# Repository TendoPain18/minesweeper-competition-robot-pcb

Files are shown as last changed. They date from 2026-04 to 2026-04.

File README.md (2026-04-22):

# Minesweeper Competition Robot — PCB Design 🤖💣

Custom KiCad-designed PCBs for a minesweeper competition robot, consisting of a **Control PCB** housing the main microcontroller and sensing/driving circuitry, and a **Power PCB** acting as a smart relay system for safely switching robot subsystems on and off.

<div align="center">
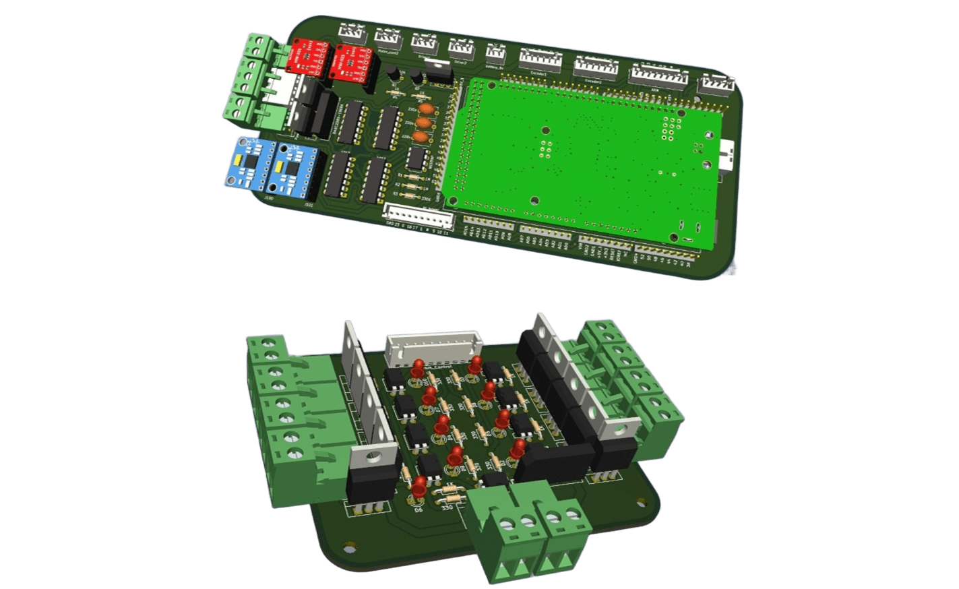
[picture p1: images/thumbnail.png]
Minesweeper Robot PCBs
  
</div>

<br>
<div align="center">
  <a href="https://codeload.github.com/TendoPain18/minesweeper-competition-robot-pcb/legacy.zip/main">
    
  </a>
</div>

## 📋 About

Both PCBs were fully designed from schematic to layout in **KiCad** and manufactured as real printed circuit boards. The two boards work together: the Control PCB handles all logic, motor driving, sensing, and protection, while the Power PCB receives switching commands from the Control PCB and safely controls power delivery to the robot's subsystems.

## 🛠️ Tools Used

- **KiCad** — Schematic capture and PCB layout
- **Arduino IDE** — Firmware for the Arduino Mega

---

## 🟦 Control PCB

The brain of the robot. Hosts the microcontroller and all peripheral circuitry needed to drive motors, read sensors, and manage safe shutdown.

<div align="center">
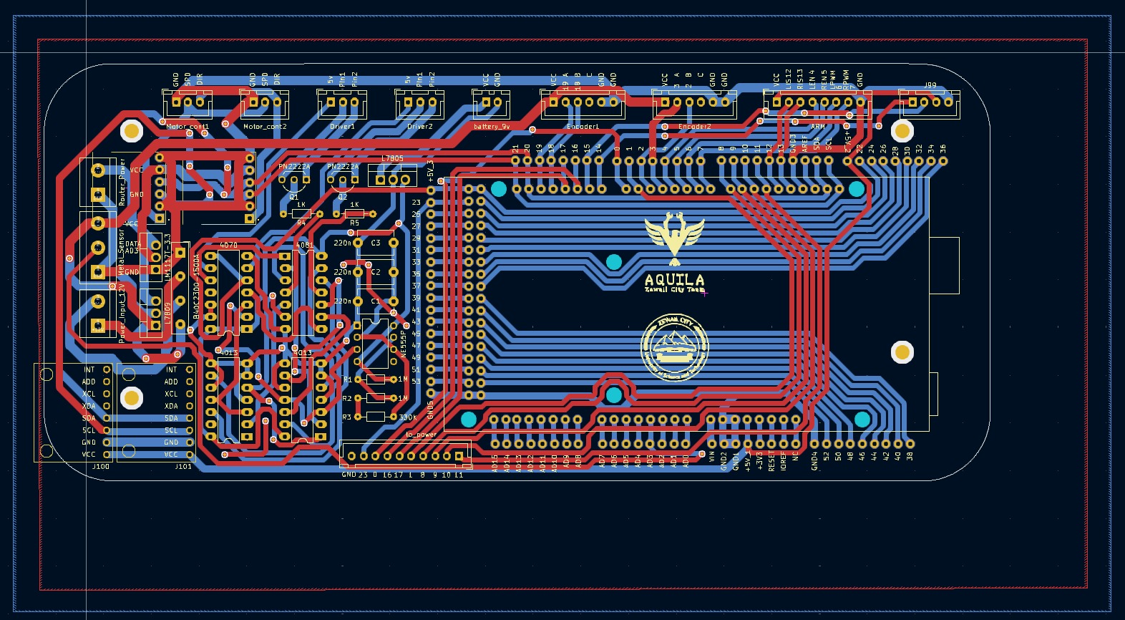
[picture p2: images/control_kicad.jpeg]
Control PCB KiCad Layout
  
</div>

<div align="center">
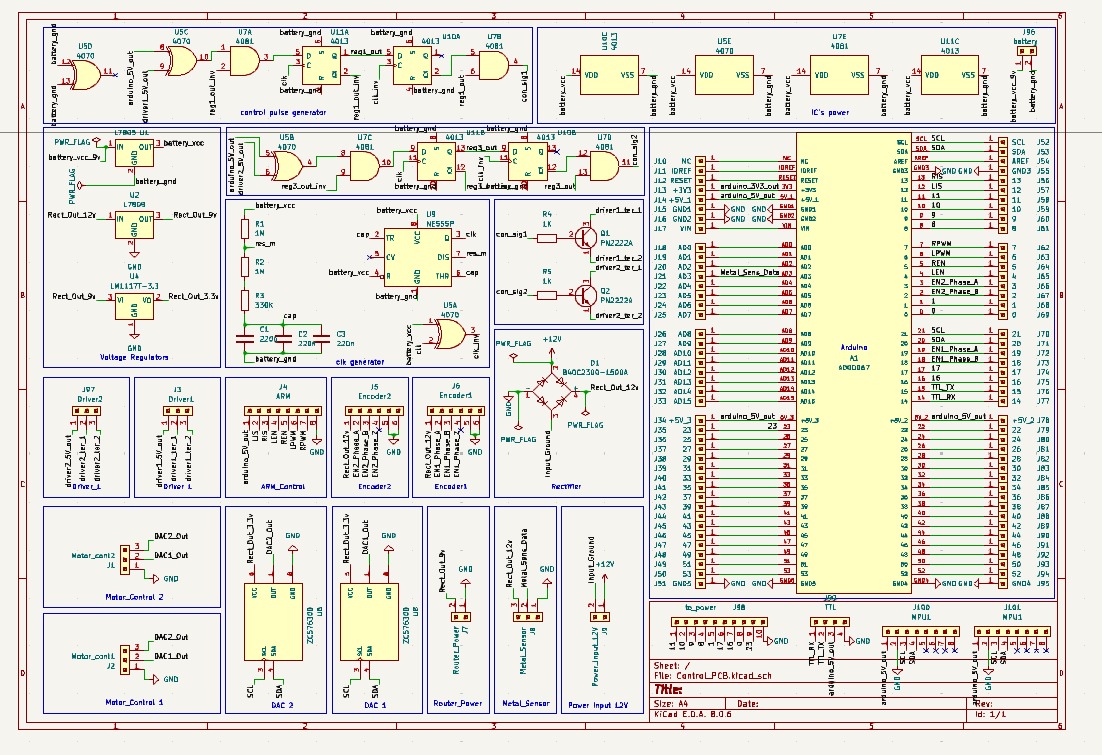
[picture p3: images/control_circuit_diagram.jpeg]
Control Circuit Diagram
  
</div>

### Key Components

- **Arduino Mega** — Main microcontroller
- **Two HW-315 Motor Driver Modules** — Drive the main locomotion motors
- **H-Bridge** — Additional motor driving stage
- **Two MPU-6050 IMUs** — Inertial measurement units for orientation sensing
- **Auto Safe-Shutdown Circuit** — Capacitor-backed circuit using ICs, capacitors, and resistors that detects power loss and safely closes the system before supply rails collapse

### Connector Pins / Interfaces

| Interface | Description |
|---|---|
| Motor Control ×2 | PWM/direction signals for drive motors |
| Motor Driver ×2 | Power outputs to HW-315 modules |
| Encoder ×2 | Quadrature encoder inputs for wheel odometry |
| Arm Motor | Control signal for the mine-detection arm |
| 9V Battery | Main power input |
| Power PCB Link | Control signals sent to the Power PCB |

### PCB Photos

<div align="center">
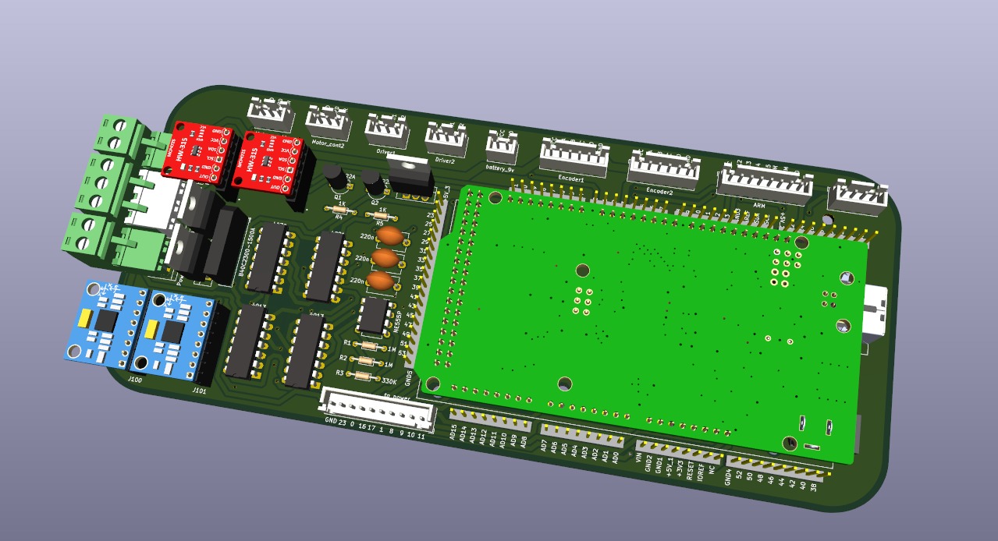
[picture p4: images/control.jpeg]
Control PCB
  
</div>

<div align="center">
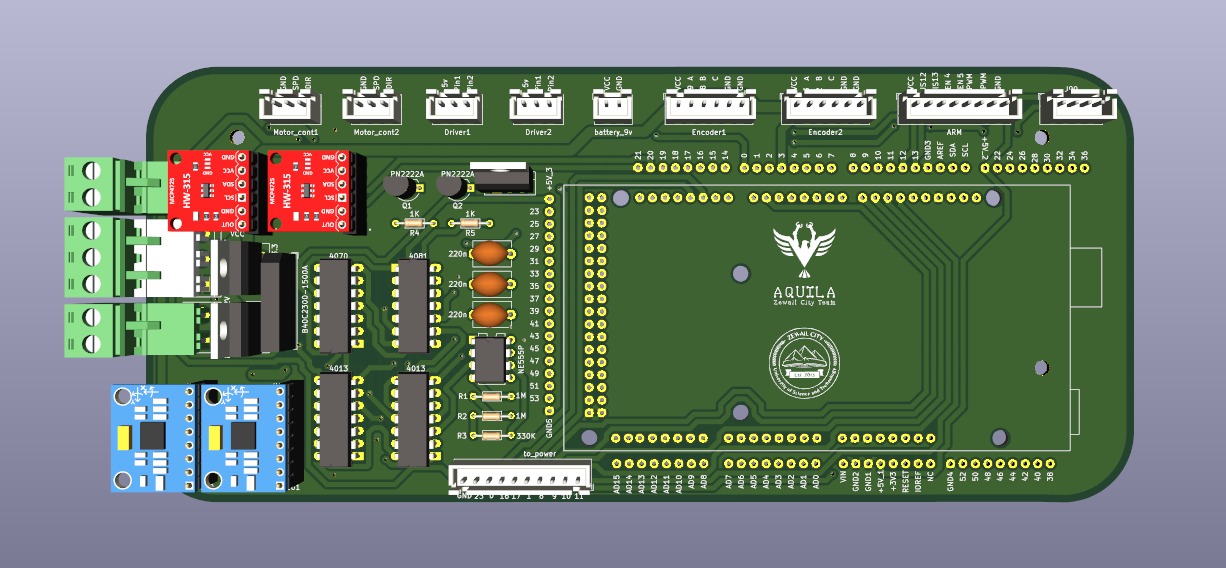
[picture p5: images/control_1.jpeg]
Control PCB View 1
  
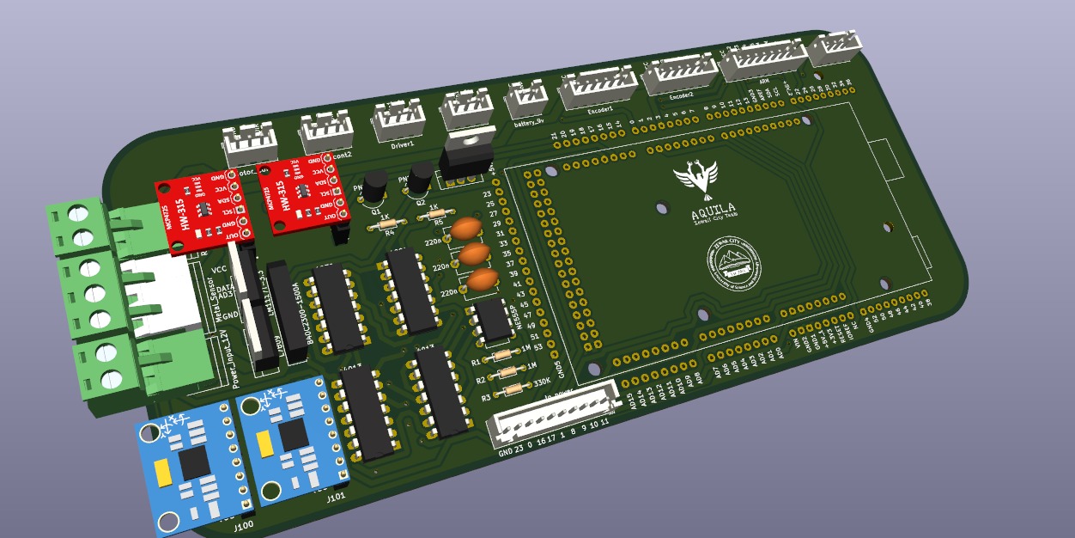
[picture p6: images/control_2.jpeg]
Control PCB View 2
  
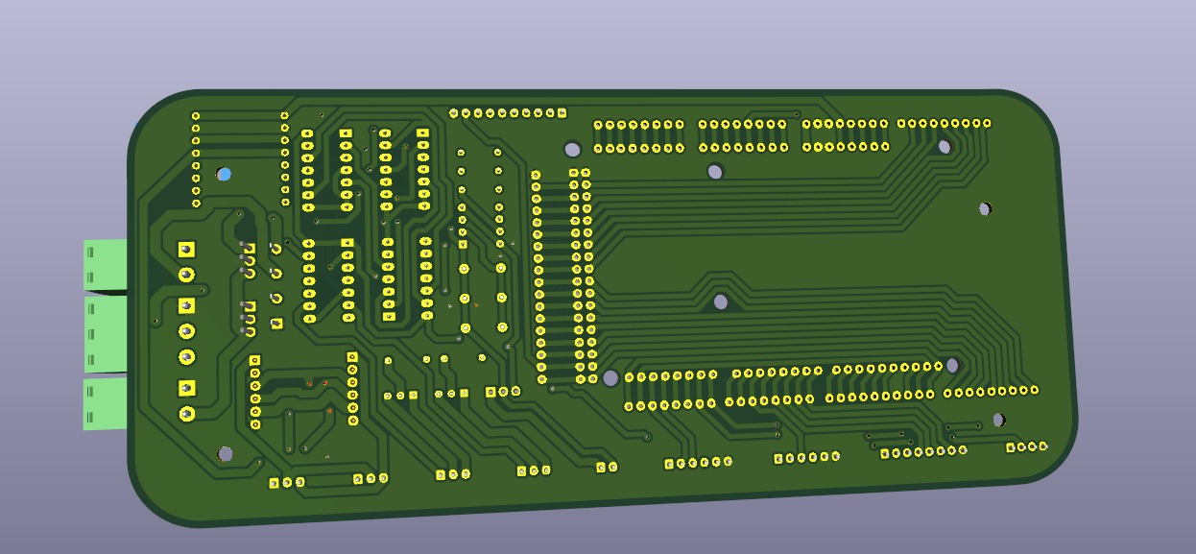
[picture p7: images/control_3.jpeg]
Control PCB View 3
  
</div>

### Safe Shutdown Circuit

A key protection feature of the Control PCB is the automatic safe-shutdown circuit. When the power supply is cut or drops below a safe threshold, the capacitor bank holds enough energy to allow the ICs to complete a controlled shutdown sequence, preventing state corruption and protecting the motor drivers from abrupt power loss.

---

## 🟥 Power PCB

Acts as a smart relay board, receiving switching signals from the Control PCB and toggling power to the robot's subsystems in a safe, controlled manner.

<div align="center">
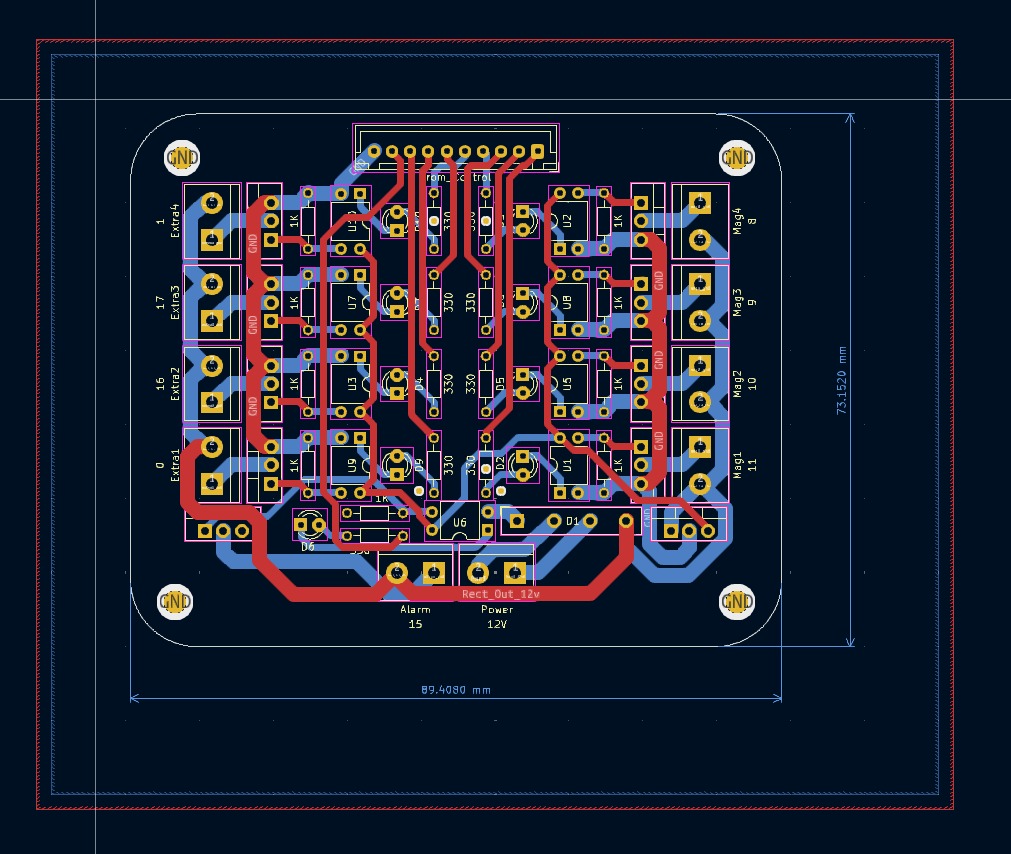
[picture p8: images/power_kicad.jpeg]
Power PCB KiCad Layout
  
</div>

<div align="center">
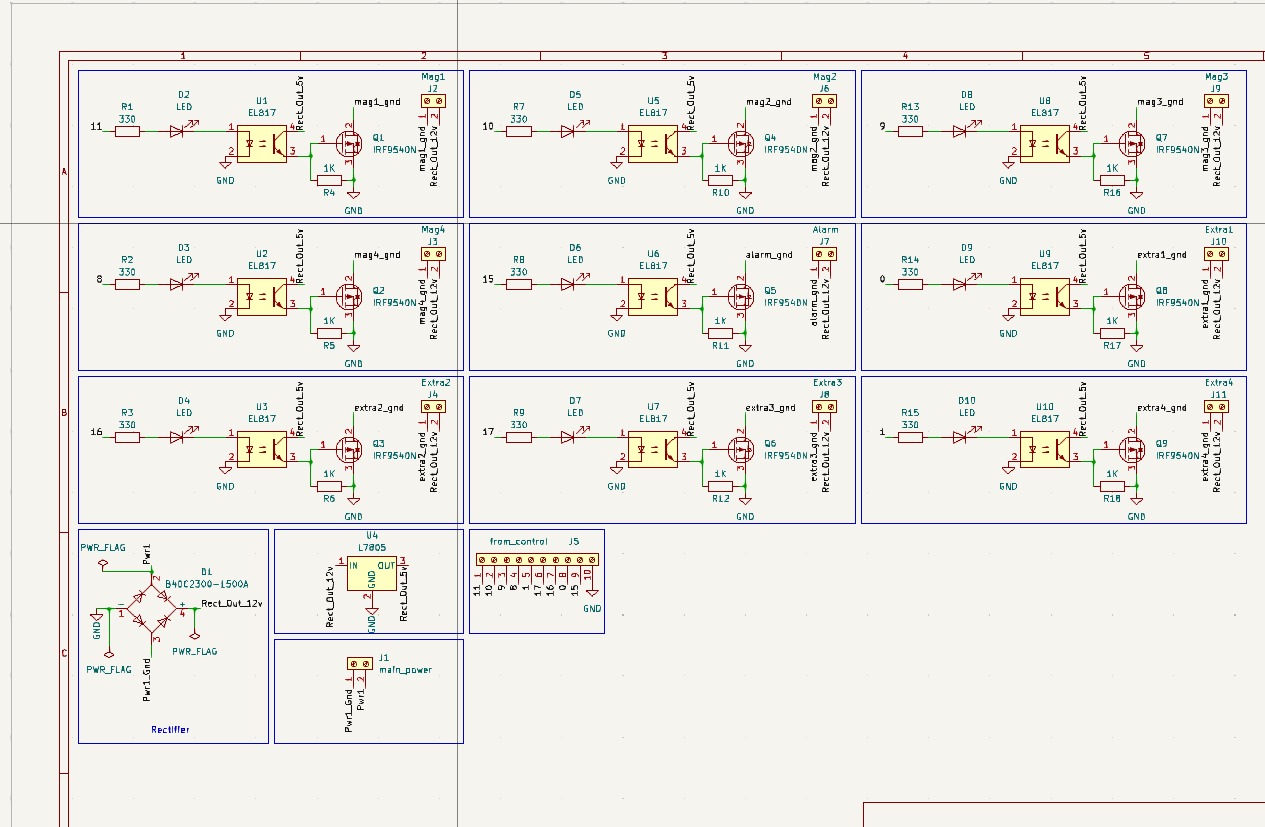
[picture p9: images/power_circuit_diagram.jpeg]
Power Circuit Diagram
  
</div>

### Key Features

- Receives control signals from the Control PCB
- Safely switches power to robot subsystems on and off
- Protects against back-EMF and switching transients
- Designed for low-resistance power paths to minimise losses

### PCB Photos

<div align="center">
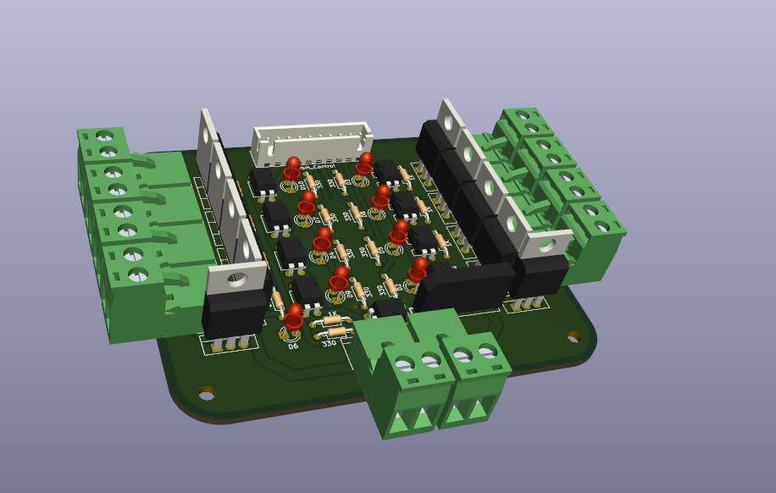
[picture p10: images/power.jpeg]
Power PCB
  
</div>

<div align="center">
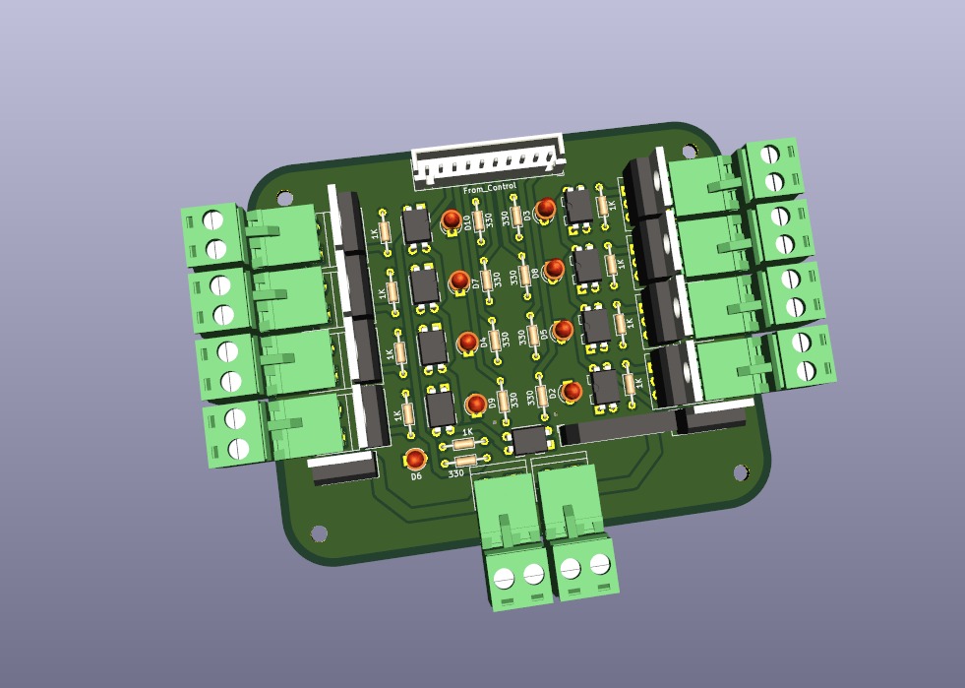
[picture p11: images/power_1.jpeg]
Power PCB View 1
  
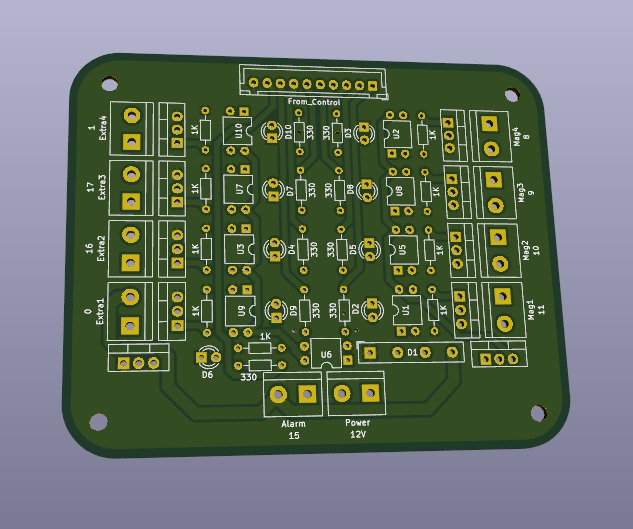
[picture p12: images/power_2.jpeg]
Power PCB View 2
  
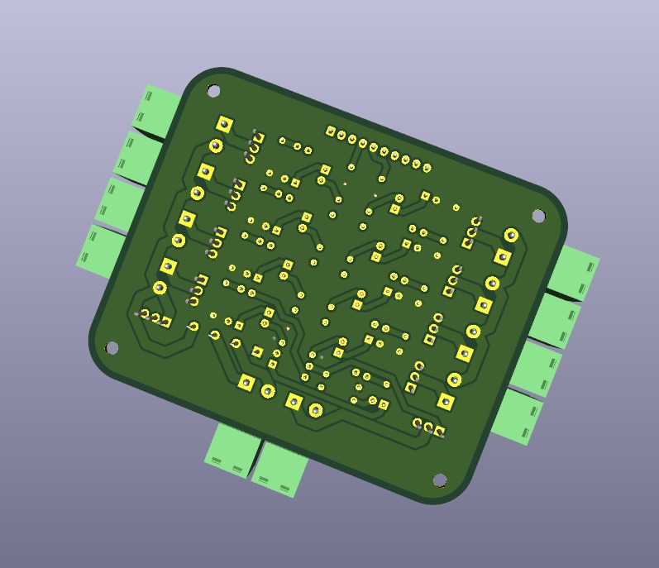
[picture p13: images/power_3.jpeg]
Power PCB View 3
  
</div>

---

## 🖨️ Manufactured Boards

<div align="center">
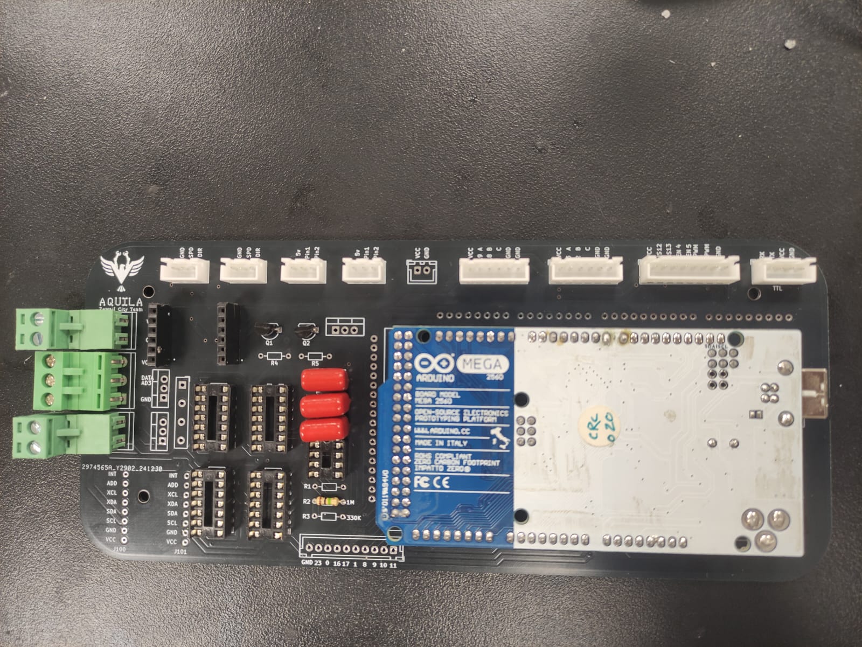
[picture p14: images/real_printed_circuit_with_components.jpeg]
Real Printed Circuit with Components
  
</div>

*Fully assembled and populated PCBs ready for robot integration*

---

## 📄 License

This project is licensed under the MIT License - see the [LICENSE](LICENSE) file for details.

## 🙏 Acknowledgments

- KiCad open-source EDA tool
- Competition organizers for the design challenge

## <!-- CONTACT -->
<div id="toc" align="center">
  <ul style="list-style: none">
    <summary>
      <h2 align="center">
        🚀
        CONTACT ME
        🚀
      </h2>
    </summary>
  </ul>
</div>
<table align="center" style="width: 100%; max-width: 600px;">
<tr>
  <td style="width: 20%; text-align: center;">
    <a href="https://www.linkedin.com/in/amr-ashraf-86457134a/" target="_blank">
      
    </a>
  </td>
  <td style="width: 20%; text-align: center;">
    <a href="https://github.com/TendoPain18" target="_blank">
      
    </a>
  </td>
  <td style="width: 20%; text-align: center;">
    <a href="mailto:amrgadalla01@gmail.com">
      
    </a>
  </td>
  <td style="width: 20%; text-align: center;">
    <a href="https://www.facebook.com/amr.ashraf.7311/" target="_blank">
      
    </a>
  </td>
  <td style="width: 20%; text-align: center;">
    <a href="https://wa.me/201019702121" target="_blank">
      
    </a>
  </td>
</tr>
</table>
<!-- END CONTACT -->

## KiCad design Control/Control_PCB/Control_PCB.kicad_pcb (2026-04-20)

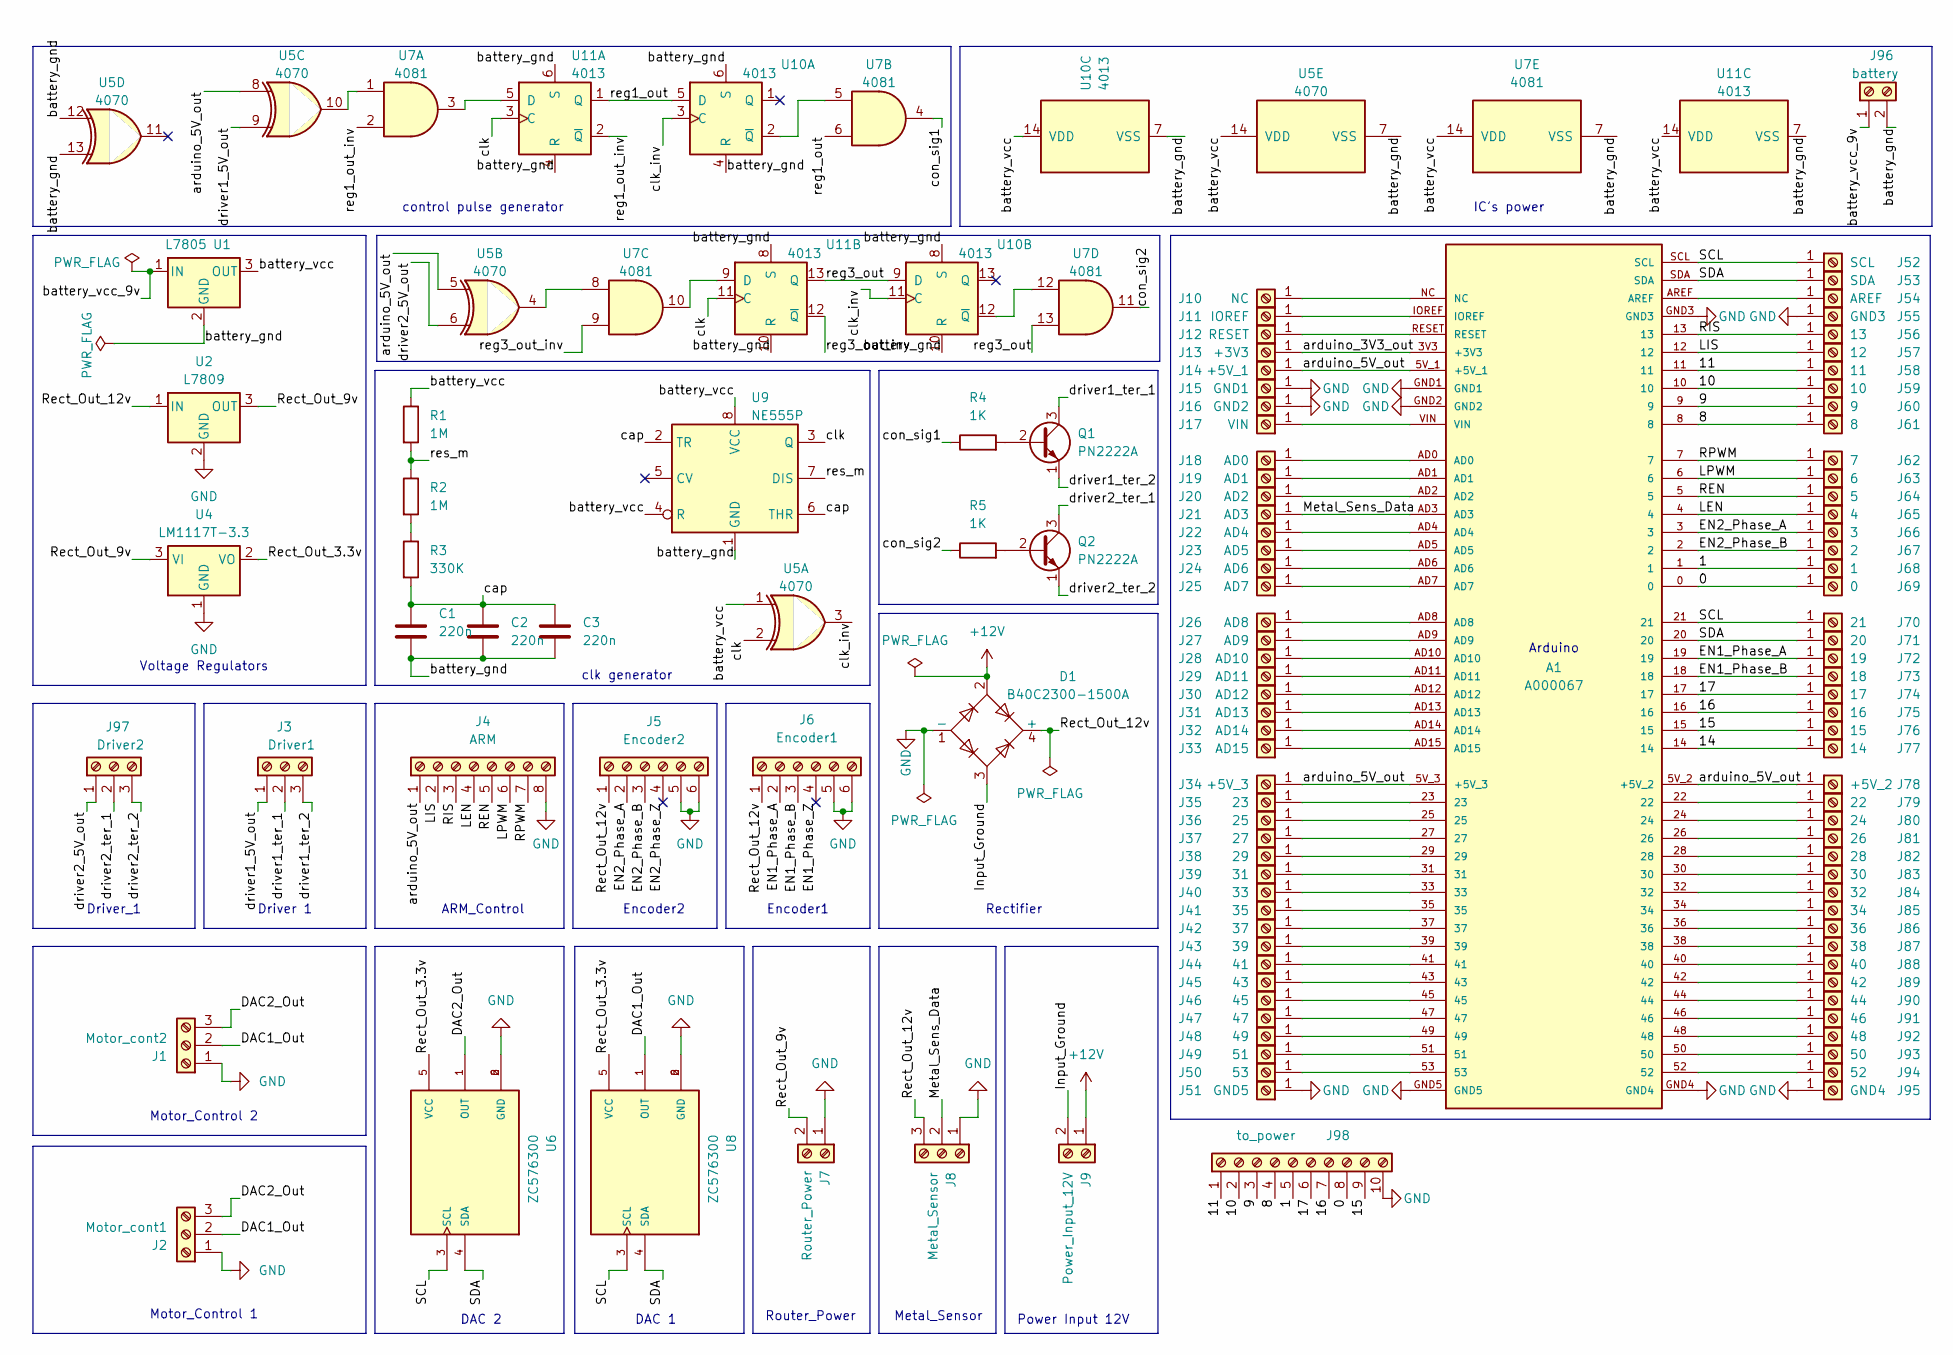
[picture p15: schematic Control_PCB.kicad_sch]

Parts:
A1: A000067; Arduino_Mega
C1, C2, C3: 220n; C_Disc_D7.5mm_W5.0mm_P7.50mm
D1: B40C2300-1500A; Diode_Bridge_19.0x3.5x10.0mm_P5.0mm
J1: Motor_cont2; JST_XH_B3B-XH-A_1x03_P2.50mm_Vertical
J2: Motor_cont1; JST_XH_B3B-XH-A_1x03_P2.50mm_Vertical
J3: Driver1; JST_XH_B3B-XH-A_1x03_P2.50mm_Vertical
J4: ARM; JST_XH_B8B-XH-A_1x08_P2.50mm_Vertical
J5: Encoder2; JST_XH_B6B-XH-A_1x06_P2.50mm_Vertical
J6: Encoder1; JST_XH_B6B-XH-A_1x06_P2.50mm_Vertical
J7: Router_Power; TerminalBlock_bornier-2_P5.08mm
J8: Metal_Sensor; TerminalBlock_bornier-3_P5.08mm
J9: Power_Input_12V; TerminalBlock_bornier-2_P5.08mm
J10: NC; Pin_Hole_0.9
J11: IOREF; Pin_Hole_0.9
J12: RESET; Pin_Hole_0.9
J13: +3V3; Pin_Hole_0.9
J14: +5V_1; Pin_Hole_0.9
J15: GND1; Pin_Hole_0.9
J16: GND2; Pin_Hole_0.9
J17: VIN; Pin_Hole_0.9
J18: AD0; Pin_Hole_0.9
J19: AD1; Pin_Hole_0.9
J20: AD2; Pin_Hole_0.9
J21: AD3; Pin_Hole_0.9
J22: AD4; Pin_Hole_0.9
J23: AD5; Pin_Hole_0.9
J24: AD6; Pin_Hole_0.9
J25: AD7; Pin_Hole_0.9
J26: AD8; Pin_Hole_0.9
J27: AD9; Pin_Hole_0.9
J28: AD10; Pin_Hole_0.9
J29: AD11; Pin_Hole_0.9
J30: AD12; Pin_Hole_0.9
J31: AD13; Pin_Hole_0.9
J32: AD14; Pin_Hole_0.9
J33: AD15; Pin_Hole_0.9
J34: +5V_3; Pin_Hole_0.9
J35: 23; Pin_Hole_0.9
J36: 25; Pin_Hole_0.9
J37: 27; Pin_Hole_0.9
J38: 29; Pin_Hole_0.9
J39: 31; Pin_Hole_0.9
J40: 33; Pin_Hole_0.9
J41: 35; Pin_Hole_0.9
J42: 37; Pin_Hole_0.9
J43: 39; Pin_Hole_0.9
J44: 41; Pin_Hole_0.9
J45: 43; Pin_Hole_0.9
J46: 45; Pin_Hole_0.9
J47: 47; Pin_Hole_0.9
J48: 49; Pin_Hole_0.9
J49: 51; Pin_Hole_0.9
J50: 53; Pin_Hole_0.9
J51: GND5; Pin_Hole_0.9
J52: SCL; Pin_Hole_0.9
J53: SDA; Pin_Hole_0.9
J54: AREF; Pin_Hole_0.9
J55: GND3; Pin_Hole_0.9
J56: 13; Pin_Hole_0.9
J57: 12; Pin_Hole_0.9
J58: 11; Pin_Hole_0.9
J59: 10; Pin_Hole_0.9
J60: 9; Pin_Hole_0.9
J61: 8; Pin_Hole_0.9
J62: 7; Pin_Hole_0.9
J63: 6; Pin_Hole_0.9
J64: 5; Pin_Hole_0.9
J65: 4; Pin_Hole_0.9
J66: 3; Pin_Hole_0.9
J67: 2; Pin_Hole_0.9
J68: 1; Pin_Hole_0.9
J69: 0; Pin_Hole_0.9
J70: 21; Pin_Hole_0.9
J71: 20; Pin_Hole_0.9
J72: 19; Pin_Hole_0.9
J73: 18; Pin_Hole_0.9
J74: 17; Pin_Hole_0.9
J75: 16; Pin_Hole_0.9
J76: 15; Pin_Hole_0.9
J77: 14; Pin_Hole_0.9
J78: +5V_2; Pin_Hole_0.9
J79: 22; Pin_Hole_0.9
J80: 24; Pin_Hole_0.9
J81: 26; Pin_Hole_0.9
J82: 28; Pin_Hole_0.9
J83: 30; Pin_Hole_0.9
J84: 32; Pin_Hole_0.9
J85: 34; Pin_Hole_0.9
J86: 36; Pin_Hole_0.9
J87: 38; Pin_Hole_0.9
J88: 40; Pin_Hole_0.9
J89: 42; Pin_Hole_0.9
J90: 44; Pin_Hole_0.9
J91: 46; Pin_Hole_0.9
J92: 48; Pin_Hole_0.9
J93: 50; Pin_Hole_0.9
J94: 52; Pin_Hole_0.9
J95: GND4; Pin_Hole_0.9
J96: battery; JST_XH_B2B-XH-A_1x02_P2.50mm_Vertical
J97: Driver2; JST_XH_B3B-XH-A_1x03_P2.50mm_Vertical
J98: to_power; JST_XH_B10B-XH-A_1x10_P2.50mm_Vertical
Q1, Q2: PN2222A; TO-92L_Inline_Wide
R1, R2: 1M; R_Axial_DIN0204_L3.6mm_D1.6mm_P7.62mm_Horizontal
R3: 330K; R_Axial_DIN0204_L3.6mm_D1.6mm_P7.62mm_Horizontal
R4, R5: 1K; R_Axial_DIN0204_L3.6mm_D1.6mm_P7.62mm_Horizontal
U1: L7805; TO-220-3_Vertical
U2: L7809; TO-220-3_Vertical
U4: LM1117T-3.3; TO-220-3_Vertical
U5: 4070; DIP-14_W7.62mm_LongPads
U6, U8: ZC576300; MODULE_ZC576300; PARTREV v14
U7: 4081; DIP-14_W7.62mm_LongPads
U9: NE555P; DIP-8_W7.62mm
U10, U11: 4013; DIP-14_W7.62mm_LongPads

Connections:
+12V: D1.2, J9.1
/0: A1.0, J69.1, J98.8
/1: A1.1, J68.1, J98.5
/8: A1.8, J61.1, J98.4
/9: A1.9, J60.1, J98.3
/10: A1.10, J59.1, J98.2
/11: A1.11, J58.1, J98.1
/14: A1.14, J77.1
/15: A1.15, J76.1, J98.9
/16: A1.16, J75.1, J98.7
/17: A1.17, J74.1, J98.6
/DAC1_Out: J1.2, J2.2, U8.1 (OUT)
/DAC2_Out: J1.3, J2.3, U6.1 (OUT)
/EN1_Phase_A: A1.19, J6.2, J72.1
/EN1_Phase_B: A1.18, J6.3, J73.1
/EN1_Phase_Z: J6.4
/EN2_Phase_A: A1.3, J5.2, J66.1
/EN2_Phase_B: A1.2, J5.3, J67.1
/EN2_Phase_Z: J5.4
/Input_Ground: D1.3, J9.2
/LEN: A1.4, J4.4, J65.1
/LIS: A1.12, J4.2, J57.1
/LPWM: A1.6, J4.6, J63.1
/Metal_Sens_Data: A1.AD3, J8.2, J21.1
/REN: A1.5, J4.5, J64.1
/RIS: A1.13, J4.3, J56.1
/RPWM: A1.7, J4.7, J62.1
/Rect_Out_3.3v: U4.2 (VO), U6.5 (VCC), U8.5 (VCC)
/Rect_Out_9v: J7.2, U2.3 (OUT), U4.3 (VI)
/Rect_Out_12v: D1.4 (+), J5.1, J6.1, J8.3, U2.1 (IN)
/SCL: A1.21, A1.SCL, J52.1, J70.1, U6.3 (SCL), U8.3 (SCL)
/SDA: A1.20, A1.SDA, J53.1, J71.1, U6.4 (SDA), U8.4 (SDA)
/arduino_3V3_out: A1.3V3 (+3V3), J13.1
/arduino_5V_out: A1.5V_1 (+5V_1), A1.5V_2 (+5V_2), A1.5V_3 (+5V_3), J4.1, J14.1, J34.1, J78.1, U5.5, U5.8
/battery_gnd: C1.2, C2.2, C3.2, J96.2, U1.2 (GND), U5.7 (VSS), U5.12, U5.13, U7.7 (VSS), U9.1 (GND), U10.4 (R), U10.6 (S), U10.7 (VSS), U10.8 (S), U10.10 (R), U11.4 (R), U11.6 (S), U11.7 (VSS), U11.8 (S), U11.10 (R)
/battery_vcc: R1.1, U1.3 (OUT), U5.1, U5.14 (VDD), U7.14 (VDD), U9.4 (R), U9.8 (VCC), U10.14 (VDD), U11.14 (VDD)
/battery_vcc_9v: J96.1, U1.1 (IN)
/cap: C1.1, C2.1, C3.1, R3.2, U9.2 (TR), U9.6 (THR)
/clk: U5.2, U9.3 (Q), U11.3 (C), U11.11 (C)
/clk_inv: U5.3, U10.3 (C), U10.11 (C)
/con_sig1: R4.1, U7.4
/con_sig2: R5.1, U7.11
/driver1_5V_out: J3.1, U5.9
/driver1_ter_1: J3.2, Q1.3 (C)
/driver1_ter_2: J3.3, Q1.1 (E)
/driver2_5V_out: J97.1, U5.6
/driver2_ter_1: J97.2, Q2.3 (C)
/driver2_ter_2: J97.3, Q2.1 (E)
/reg1_out: U7.6, U10.5 (D), U11.1 (Q)
/reg1_out_inv: U7.2, U11.2 (~Q)
/reg3_out: U7.13, U10.9 (D), U11.13 (Q)
/reg3_out_inv: U7.9, U11.12 (~Q)
/res_m: R1.2, R2.1, U9.7 (DIS)
GND: A1.GND1, A1.GND2, A1.GND3, A1.GND4, A1.GND5, D1.1 (-), J1.1, J2.1, J4.8, J5.5, J5.6, J6.5, J6.6, J7.1, J8.1, J15.1, J16.1, J51.1, J55.1, J95.1, J98.10, U2.2 (GND), U4.1 (GND), U6.2 (GND), U6.6 (GND), U8.2 (GND), U8.6 (GND)
unnamed: A1.NC, J10.1
unnamed: A1.IOREF, J11.1
unnamed: A1.RESET, J12.1
unnamed: A1.VIN, J17.1
unnamed: A1.AD0, J18.1
unnamed: A1.AD1, J19.1
unnamed: A1.AD2, J20.1
unnamed: A1.AD4, J22.1
unnamed: A1.AD5, J23.1
unnamed: A1.AD6, J24.1
unnamed: A1.AD7, J25.1
unnamed: A1.AD8, J26.1
unnamed: A1.AD9, J27.1
unnamed: A1.AD10, J28.1
unnamed: A1.AD11, J29.1
unnamed: A1.AD12, J30.1
unnamed: A1.AD13, J31.1
unnamed: A1.AD14, J32.1
unnamed: A1.AD15, J33.1
unnamed: A1.23, J35.1
unnamed: A1.25, J36.1
unnamed: A1.27, J37.1
unnamed: A1.29, J38.1
unnamed: A1.31, J39.1
unnamed: A1.33, J40.1
unnamed: A1.35, J41.1
unnamed: A1.37, J42.1
unnamed: A1.39, J43.1
unnamed: A1.41, J44.1
unnamed: A1.43, J45.1
unnamed: A1.45, J46.1
unnamed: A1.47, J47.1
unnamed: A1.49, J48.1
unnamed: A1.51, J49.1
unnamed: A1.53, J50.1
unnamed: A1.AREF, J54.1
unnamed: A1.22, J79.1
unnamed: A1.24, J80.1
unnamed: A1.26, J81.1
unnamed: A1.28, J82.1
unnamed: A1.30, J83.1
unnamed: A1.32, J84.1
unnamed: A1.34, J85.1
unnamed: A1.36, J86.1
unnamed: A1.38, J87.1
unnamed: A1.40, J88.1
unnamed: A1.42, J89.1
unnamed: A1.44, J90.1
unnamed: A1.46, J91.1
unnamed: A1.48, J92.1
unnamed: A1.50, J93.1
unnamed: A1.52, J94.1
unnamed: Q1.2 (B), R4.2
unnamed: Q2.2 (B), R5.2
unnamed: R2.2, R3.1
unnamed: U5.4, U7.8
unnamed: U5.10, U7.1
unnamed: U7.5, U10.2 (~Q)
unnamed: U7.12, U10.12 (~Q)
unnamed: U7.3, U11.5 (D)
unnamed: U7.10, U11.9 (D)

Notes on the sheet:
Driver_1
clk generator
Voltage Regulators
Power Input 12V
Router_Power
ARM_Control
DAC 1
IC's power
Rectifier
Encoder2
Motor_Control 1
Arduino
Encoder1
Metal_Sensor
Motor_Control 2
DAC 2
control pulse generator
Driver 1

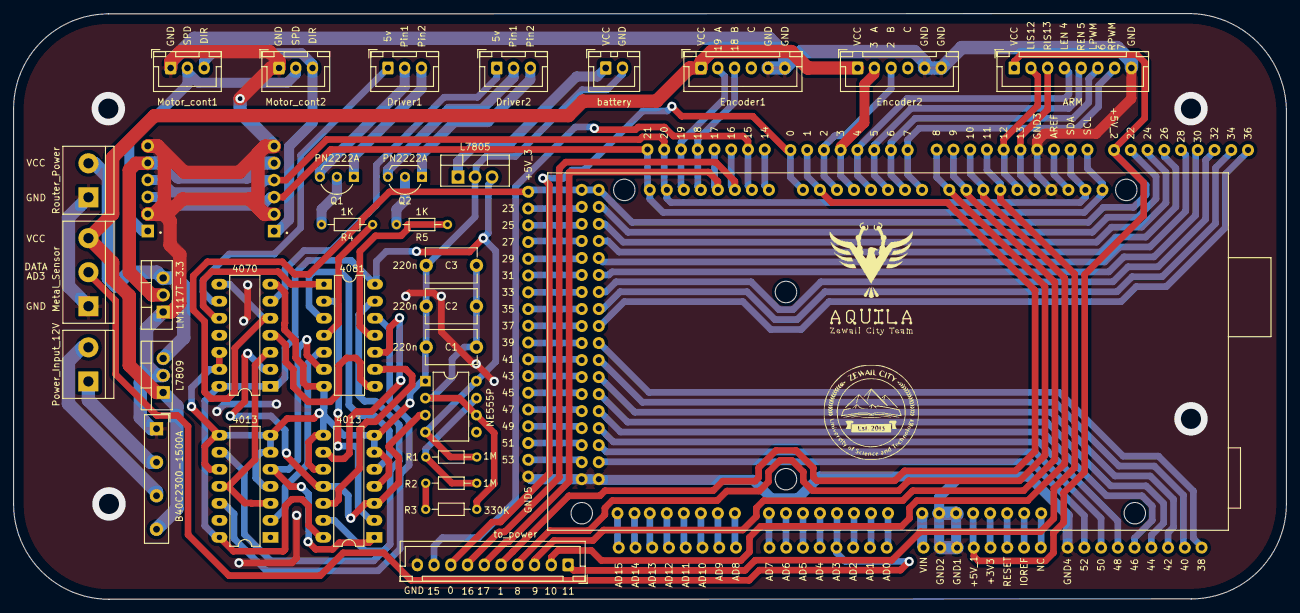
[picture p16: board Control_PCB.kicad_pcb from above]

Board: 2 copper layers, 190.0 x 87.4 mm, 120 parts (0 on the bottom side), 113 nets.

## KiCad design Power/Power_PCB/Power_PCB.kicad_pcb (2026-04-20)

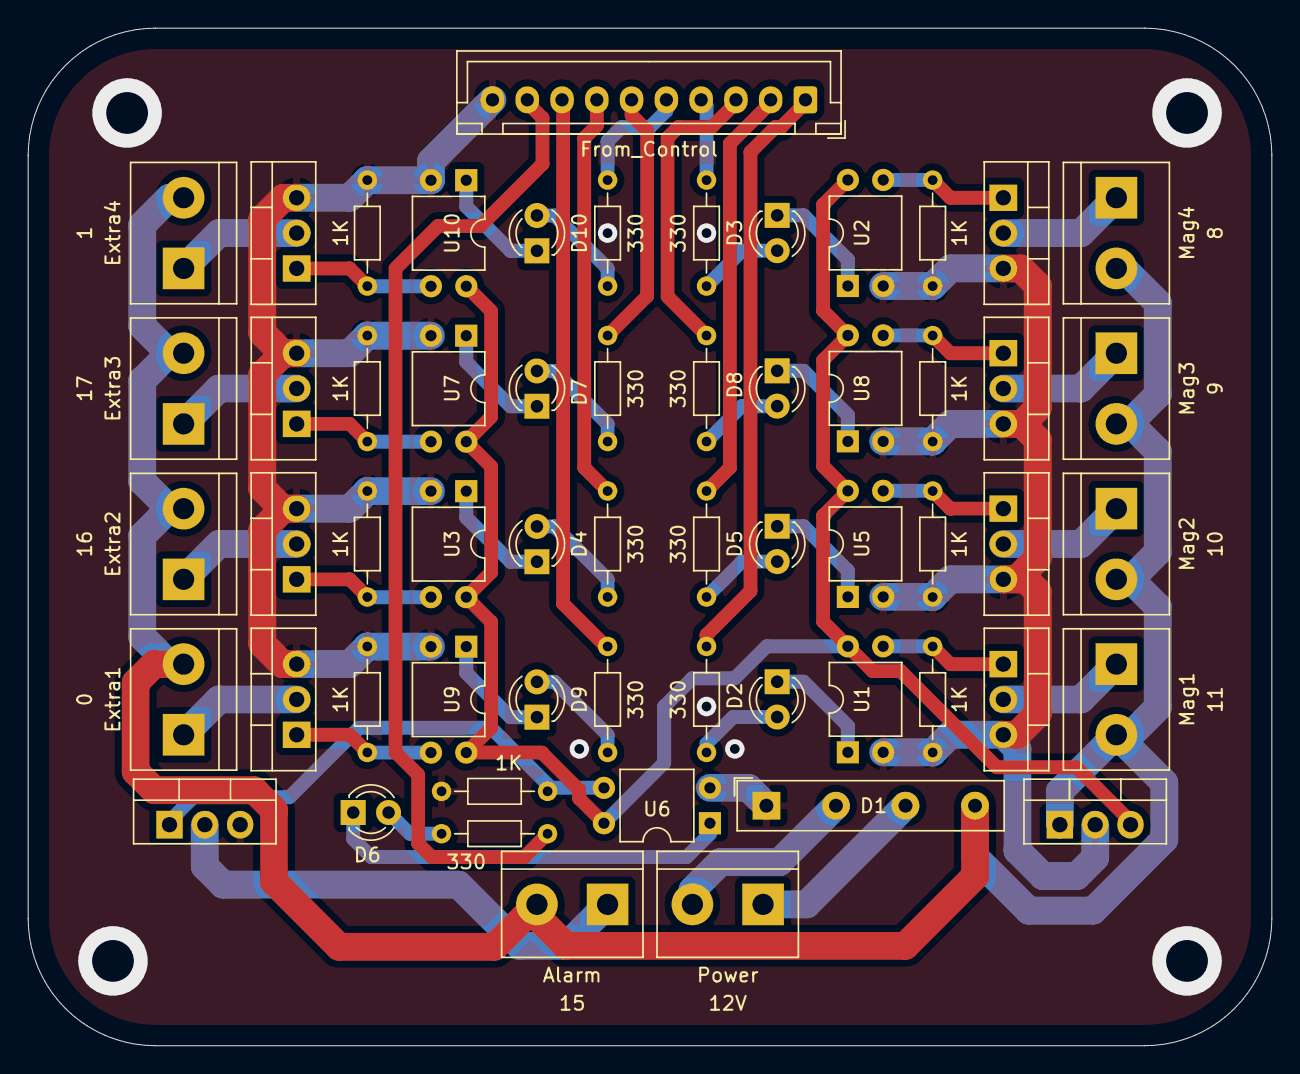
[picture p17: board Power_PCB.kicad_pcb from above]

Board: 2 copper layers, 89.4 x 73.2 mm, 58 parts (0 on the bottom side), 50 nets.

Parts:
1K, 1K#2, 1K#3, 1K#4, 1K#5, 1K#6, 1K#7, 1K#8, 1K#9: 1K; R_Axial_DIN0204_L3.6mm_D1.6mm_P7.62mm_Horizontal
330, 330#2, 330#3, 330#4, 330#5, 330#6, 330#7, 330#8, 330#9: 330; R_Axial_DIN0204_L3.6mm_D1.6mm_P7.62mm_Horizontal
Alarm: Alarm; TerminalBlock_bornier-2_P5.08mm
D1: B40C2300-1500A; Diode_Bridge_19.0x3.5x10.0mm_P5.0mm
D2, D3, D4, D5, D6, D7, D8, D9, D10: LED; LED_D3.0mm
Extra1: Extra1; TerminalBlock_bornier-2_P5.08mm
Extra2: Extra2; TerminalBlock_bornier-2_P5.08mm
Extra3: Extra3; TerminalBlock_bornier-2_P5.08mm
Extra4: Extra4; TerminalBlock_bornier-2_P5.08mm
From_Control: from_control; JST_XH_B10B-XH-A_1x10_P2.50mm_Vertical
Mag1: Mag1; TerminalBlock_bornier-2_P5.08mm
Mag2: Mag2; TerminalBlock_bornier-2_P5.08mm
Mag3: Mag3; TerminalBlock_bornier-2_P5.08mm
Mag4: Mag4; TerminalBlock_bornier-2_P5.08mm
Power: main_power; TerminalBlock_bornier-2_P5.08mm
Q1, Q2, Q3, Q4, Q5, Q6, Q7, Q8, Q9: IRF9540N; TO-220-3_Vertical
U1, U2, U3, U5, U6, U7, U8, U9, U10: EL817; DIP-4_W7.62mm
U4: L7805; TO-220-3_Vertical

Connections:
/0: 330#6.1, From_Control.8
/1: 330#7.1, From_Control.5
/8: 330.1, From_Control.4
/9: 330#8.1, From_Control.3
/10: 330#4.1, From_Control.2
/11: 330#3.1, From_Control.1
/15: 330#5.1, From_Control.9
/16: 330#2.1, From_Control.7
/17: 330#9.1, From_Control.6
/Pwr1: D1.2, Power.2
/Pwr1_Gnd: D1.3, Power.1
/Rect_Out_5v: U1.4, U2.4, U3.4, U4.3 (OUT), U5.4, U6.4, U7.4, U8.4, U9.4, U10.4
/Rect_Out_12v: Alarm.2, D1.4 (+), Extra1.2, Extra2.2, Extra3.2, Extra4.2, Mag1.2, Mag2.2, Mag3.2, Mag4.2, U4.1 (IN)
/alarm_gnd: Alarm.1, Q5.2 (D)
/extra1_gnd: Extra1.1, Q8.2 (D)
/extra2_gnd: Extra2.1, Q3.2 (D)
/extra3_gnd: Extra3.1, Q6.2 (D)
/extra4_gnd: Extra4.1, Q9.2 (D)
/mag1_gnd: Mag1.1, Q1.2 (D)
/mag2_gnd: Mag2.1, Q4.2 (D)
/mag3_gnd: Mag3.1, Q7.2 (D)
/mag4_gnd: Mag4.1, Q2.2 (D)
GND: 1K.2, 1K#2.2, 1K#3.2, 1K#4.2, 1K#5.2, 1K#6.2, 1K#7.2, 1K#8.2, 1K#9.2, D1.1 (-), From_Control.10, Q1.3 (S), Q2.3 (S), Q3.3 (S), Q4.3 (S), Q5.3 (S), Q6.3 (S), Q7.3 (S), Q8.3 (S), Q9.3 (S), U1.2, U2.2, U3.2, U4.2 (GND), U5.2, U6.2, U7.2, U8.2, U9.2, U10.2
unnamed: 330#3.2, D2.2 (A)
unnamed: D2.1 (K), U1.1
unnamed: 330.2, D3.2 (A)
unnamed: D3.1 (K), U2.1
unnamed: 330#2.2, D4.2 (A)
unnamed: D4.1 (K), U3.1
unnamed: 330#4.2, D5.2 (A)
unnamed: D5.1 (K), U5.1
unnamed: 330#5.2, D6.2 (A)
unnamed: D6.1 (K), U6.1
unnamed: 330#9.2, D7.2 (A)
unnamed: D7.1 (K), U7.1
unnamed: 330#8.2, D8.2 (A)
unnamed: D8.1 (K), U8.1
unnamed: 330#6.2, D9.2 (A)
unnamed: D9.1 (K), U9.1
unnamed: 330#7.2, D10.2 (A)
unnamed: D10.1 (K), U10.1
unnamed: 1K#3.1, Q1.1 (G), U1.3
unnamed: 1K#4.1, Q2.1 (G), U2.3
unnamed: 1K#2.1, Q3.1 (G), U3.3
unnamed: 1K#6.1, Q4.1 (G), U5.3
unnamed: 1K#8.1, Q5.1 (G), U6.3
unnamed: 1K.1, Q6.1 (G), U7.3
unnamed: 1K#5.1, Q7.1 (G), U8.3
unnamed: 1K#9.1, Q8.1 (G), U9.3
unnamed: 1K#7.1, Q9.1 (G), U10.3

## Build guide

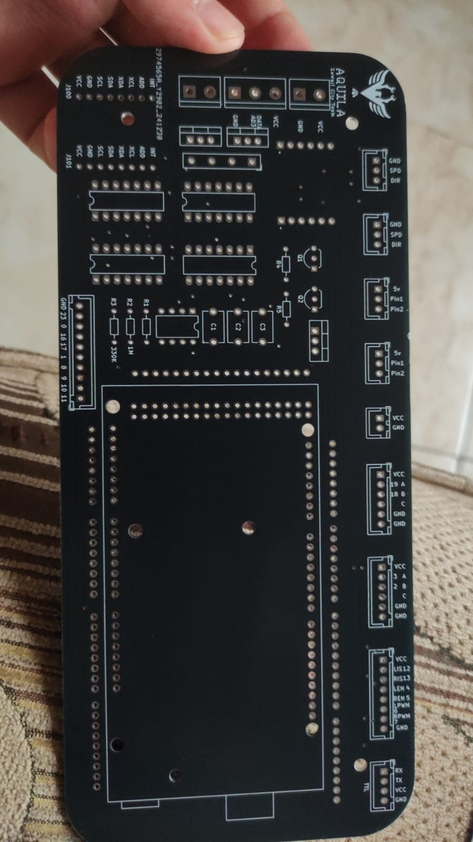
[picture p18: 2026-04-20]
images/real_printed_circuit.jpeg
